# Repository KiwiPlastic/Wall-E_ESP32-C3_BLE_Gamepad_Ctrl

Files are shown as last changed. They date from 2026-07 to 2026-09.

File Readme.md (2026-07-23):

# Wall-E ESP32-C3 with BLE Game Controller (Xbox controler)
Thie is an upgrade to the Wall-E project developed by Chillbasket

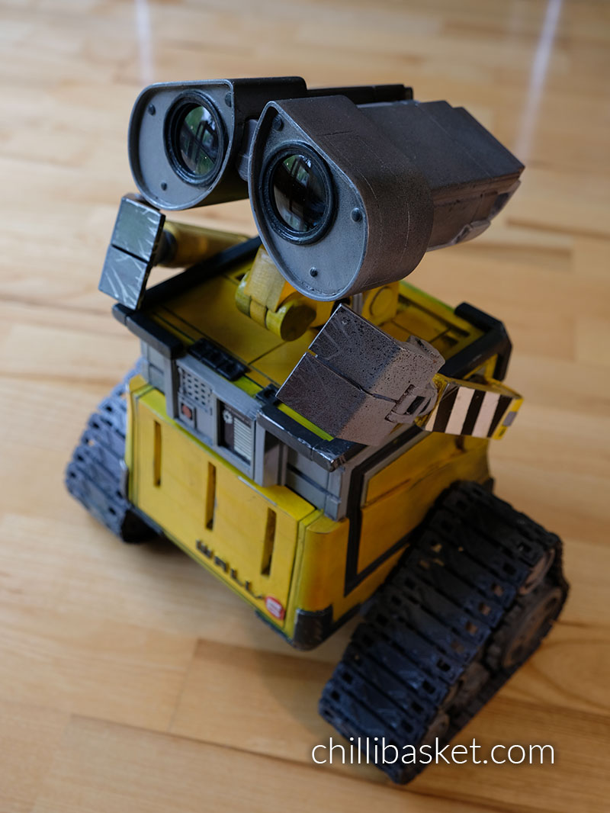
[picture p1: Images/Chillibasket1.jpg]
Walle-E Chillibasket


## 🚀 Upgrades and Features
  -	Web Server removed
  -	Added BLE Gamepad controller – Xbox controler 2026
  -	Added working Top buttons
  -	Added Bay Door Servo
  -	Controllable Bay LED light
  -	Electronics Platform – frees up Bay so can have a boot and plant etc
  -	RGB mood LED
  -	1.44 Oled feedback display
  -	All existing avaliable upgrade prints have been used and are included.
  - The only changed one is the top cover to accomidate pushbuttons
  
•	10 DOF:-
  -	Arms (2)
  -	Neck (2)
  -	Head Rotation (1)
  -	Eyes (2) 
  -	Eye Borrows (2)
  -	Bay Door (1)

•	Size:	H = 338		W = 291	D = 186

## 📦 Build & Installation

•	See this link for Wall-E Assembly Instructions and Videos by Chillbasket (https://wired.chillibasket.com/3d-printed-wall-e/) 

### Hardware: -
    1 x ESP32-C3
    1 x I2C PCA9685 16-Channel 12-bit PWM Servo Motor Driver Module
    1 x I2C PCF 8575 I/O Multiplexer
    1 x Audio Module - Mini MP3 Player Audio Module (DFPLayer)
    1 x mini-Speaker 8 or 4 ohm 3watt
    1 x 1.44 I2C OLED Display
    1 x 10mm RGB LED – common cathode 
    4 x Tactile Pushbutton with LED
    4 x 150R resistor
    1 x 4K7 Resistor
    3 x Logic Level Shifter 3v to 5v 
    1 x L298N Dual H Bridge DC Motor Driver
    10 x MG90S metal gear servos
    2 x 37mm motor with gearbox, offset shaft, 25kg, 150 rpm (Not cheap ones)
    1 x LR7843 Mosfet module
    1 x MP1482 min buck set to 2v
    1 x 1watt or 3watt LED (torch head light LED)
    2 x Buck 5amp Set to 5v and 6v
    1 x 10amp auto reset fuse
    1 x XT60 Male Connector
    16 x Bearings 10 x 15 x 4
    Misc. M3 bolts, nuts, heat inserts, heat shrink

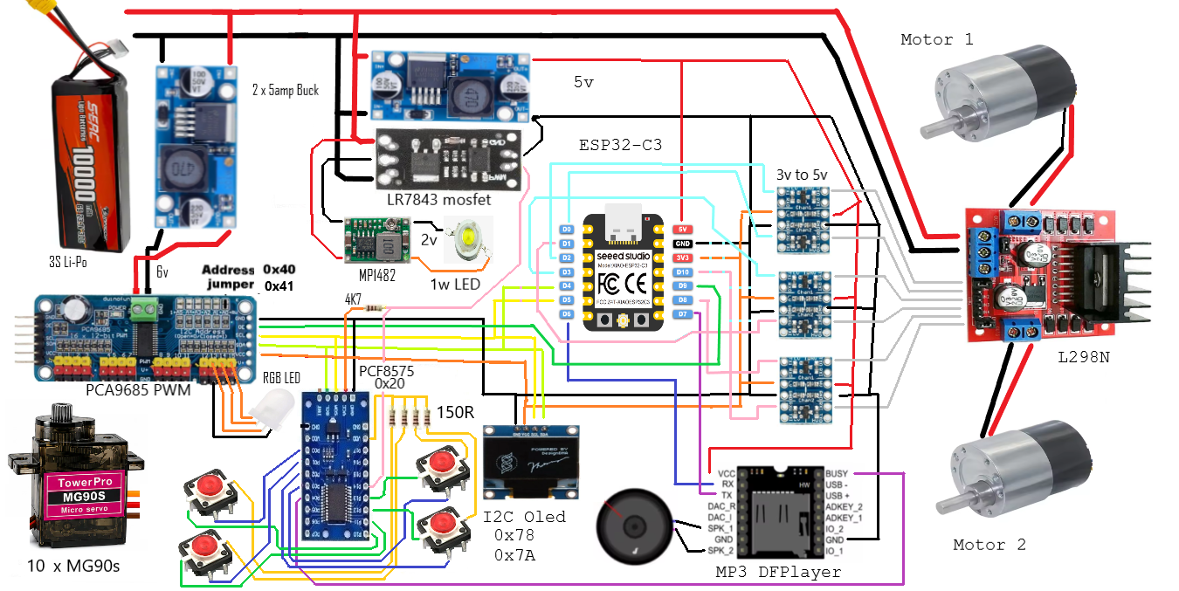
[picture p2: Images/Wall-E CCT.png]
circuit


### Servo Channel List: -
    0 Head Rotation
    1 Neck Top
    2 Neckk Bottom
    3 Eye Right
    4 Eye Left
    5 Arm Left
    6 Arm Right
    7 Eye Brow Right
    8 Eye Brow Left
    9 Bay Door
    10
    11
    12
    13 RED RGB LED
    14 GRN RGB LED
    15 BLU RGB LED



Use common Cathod 10mm RGB LED

### Notes: -
    - All moving joints need to be sanded and made to work as smoothly as possible
    - Silicon from (Starlink Installations) is useful on these joints
    - Power up PSU and adjust Bucks to 5v, 6v and 2v BEFORE connecting to main loom
    - Wire up loom and electronics, then test before securing to 3d prints
    - glue electronics floor brakets so floor is level with top of Bay door opening
    - Secure electronics to 3d prints
    - Power up with no Motor or Servo loads, test buttons, leds, oled, MP3 player, xbox controller is working
    - Connect servos and put calibration firmware in ESP32 and perform calibration (https://wired.chillibasket.com/3d-printed-wall-e/)
    - Edit main wall-E firmware to add the calibration values from IDE serial monitor, transfer to ESP32 
    - Power up Wall-E, with game controler off
    - Turn on Game controller, should enrol automatically, watch Oled
    - Test and go for gold
    - Note: Theres no Battery monitor in this code. Use a Li-Po battery monitor/buzzer on Li-Po monitor plug 






### Arduino IDE will require these library's
    - BLE-Game_Client by Tomaz bekas V0.12.1
    - ESP_Software_Serial by Dirk Kaar SNDVAPS 8.3.1
    - Adafruit SSD1306 by Adfruit v2.5.17
    - Adafruit PWM Servo Driver lib by Adfruit v 3.03 
    - Adafruit PCF8574 by Adfruit v 1.1.2
    - DFRobotDFPlayerMini by DFRobot v1.0.6
    - Wire.h - I2C library driver, Could be built into IDE Library’s

Note: at time of writting the BLE-Game_Client required a small edit in a txt file to get it working. (https://github.com/tbekas/BLE-Gamepad-Client/pull/122)
It will be fixed in newer version releases, so this edit will not always be required.

## 🛠️ Usage

### Top Push Buttons Functions: -
    RED PB - Play Prev 
    GRN PB - Play Next
    ORG PB – Autonomous Servos On/Off 
    WHT PB – Bay Door Open/Close
    
### BLE Gamepad - Xbox controler - Button Map :-
    Tracks turn left/right  	Left Stick X (hoz)      
    Tracks forward/back       Left Stick Y (Vert) 
    Head rotation           	Right Stick X
    Head Up/Down            	Right Stick Y
    Neck Bottom             	Button A + Dpad Up/Dwn
    Lhs Eye                 	Button X + Dpad Up/Dwn
    Lhs Eyebrow             	Button X + Dpad Left/Right
    Rhs Eye                 	Button B + Dpad Up/Dwn
    Rhs Eyebrow             	Button B + Dpad Left/Right
    Bay Door Open/Close      	Button Y + Dpad Left Right
    Left Arm               	  Left Trigger  + Dpad Up/Dwn
    Right Arm              	  Right Trigger + Dpad Up/Dwn
    Play Sound              	Left Bumper + Dpad Left/Right - can crash
    Motor dead zone         	Left Bumper + Dpad Up/Dwn - 0 to 250
    LEDS move               	Right Bumper + Dpad Left/Right - loop x 4
    Steering Offset         	Right Bumper + Dpad Up/Dwn -  -100 to 100
    Animation Number          ViewButton +  Dpad Up/Dwn
    Automonus Mode    	      MenuButton On/Off toggel
    Dpad Up                 	adjust up
    Dpad Down               	adjust down
    Dpad Left               	adjust left
    Dpad Right              	adjust right
    Left Stick Button
    Right Stick Button
    ShareButton
    XboxButton

## 📜 License
Distributed under the MIT License. See `LICENSE` for more information.

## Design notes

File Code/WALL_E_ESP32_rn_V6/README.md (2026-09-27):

/* * * * * * * * * * * * * * * * * * * * * * *
 *
 * Upgraded Code by:  Richard Nicholson
 * Email:    richn01@msn.com
 * based on the original project and code from Simon Bluett ( hello@chillibasket.com )
 * Version:  6.0
 * Date:     18-9-2026
 * Copyright (C) 2020, MIT License
 *
 * HOW TO USE:
 * 1. Install the following library's
 *    In the Arduino IDE, on the left, click the libary manager icon
 *       BLE-Game_Client by Tomaz bekas V0.12.1
 *       ESP_Software_Serial by Dirk Kaar SNDVAPS 8.3.1
 *       Adafruit SSD1306 by Adfruit v2.5.17
 *       Adafruit PWM Servo Driver lib by Adfruit v 3.03 
 *       Adafruit PCF8574 by Adfruit v 1.1.2
 *       DFRobotDFPlayerMini by DFRobot v1.0.6
 *       I2C Wire driver, Could be built in to IDE 
 *    
 * 2. Calibrate the servo motors, using the calibration sketch provided in the
 *    GitHub repository. Paste the calibrated values between lines 296 to 305.
 * 3. Upload the sketch to the micro-controller, and open the serial monitor 
 *    at a baud rate of 115200.
 * 4. Turn Game Pad on, should automaticaly enrol
 * 5. Additional instructions and hints can be found at:
 *    https://wired.chillibasket.com/3d-printed-wall-e/
 *
 * * * * * * * * * * * * * * * * * * * * * * *

Summary of upgardes
 - Removed web server and associated libarys due to documented memory leak
 - Got Track motors working correctly
 - Got DFPlayer starting more reliably
 - Added I2C Oled display
 - Added I2C PCF8575 I/O Expander
 - Added BLE Gamepad controler libaray, note needs edit in c++ files to get working
 - Fixed Hardware crash coursed by BLE driver. Hardware serial for DFPlayer stopped working
 - Added ESP_Soft_Serial, DFPayer working with BLE driver (Xbox)
 - Expose all xbox buttons and vibration
 - Map xbox buttons to Wall-E CLI servos and controls
 - Added 4 x Push Buttons and LEDs
 - Added DFPlay Busy feed back via PCF8575
 - Added Bay Door Servo
 - Added Bay LED light
 - Added RGB mood LED on PWM module
 - Added different simple Oled display
 - RGB Led
 
NOTE: BLE Controler should be OFF on Wall-E Power up
 
// BLE Gamepad - Xbox controler - button map     Needs updating 18-9-26
    Tracks turn left/right  Left Stick X (hoz)      
    Tracks forward/back     Left Stick Y (Vert) 
    Head rotation           Right Stick X
    Head Up/Down            Right Stick Y
    Neck Bottom             Button A + Dpad Up/Dwn
    Lhs Eye                 Button X + Dpad Up/Dwn
    Lhs Eyebrow             Button X + Dpad Left/Right
    Rhs Eye                 Button B + Dpad Up/Dwn
    Rhs Eyebrow             Button B + Dpad Left/Right
    Door Open/Close         Button Y + Dpad Left Right
    Left Arm                Left Trigger  + Dpad Up/Dwn
    Right Arm               Right Trigger + Dpad Up/Dwn
    Play Sound              Left Bumper + Dpad Left/Right - can crash
    Motor dead zone         Left Bumper + Dpad Up/Dwn - 0 to 250
    LEDS move               Right Bumper + Dpad Left/Right - loop x 4
    Steering Offset         Right Bumper + Dpad Up/Dwn -  -100 to 100
    Animation Number        ViewButton +  Dpad Up/Dwn
    Automonus Servo Mode    MenuButton On/Off toggel
    Dpad Up                 adjust up
    Dpad Down               adjust down
    Dpad Left               adjust left
    Dpad Right              adjust right
    Left Stick Button
    Right Stick Button
    ShareButton
    XboxButton

 // LED Push Buttons on Front
    RED_PB = Play Prev
    GRN_PB = PlaY current
    ORG_PB = Play next
    WHT_PB = Door Open/Close

 //  CLI
    Wn -100 to 100 Motor turn Left/Right Ctrl
    Yn -100 to 100 Motor Forward/Reverse
    sn -100 to 100 Steering Offset
    On 0 to 250 Motor dead zone
    An  Animation number 
    Mn  0 to 1 Autoomonus Servo Mode on/off
    Ln 0 to 100 Left Arm move 
    Rn 0 to 100 Right Arm Movement
    Bn 0 to 100 Neck Bottom
    Tn 0 to 100 Neck Top        
    Gn 0 to 100 Head Rotation
    En 0 to 100 Lhs Eye
    Un 0 to 100 Rhs Eye
    Cn 0 to 100 Lhs Eyebrow
    Vn 0 to 100 Rhs Eyebrow
    Dn 0 to 1 Door open/close
    w Move forwrad
    q Stop
    s Backward
    a Drive & look Left
    d Drive and look Right
    j Left head Tilt
    l Right Head tilt
    i Sad Head
    k Head Neutral
    f Head Up
    g Head Forward
    h Head Down
    b LHS Arm Low,RHS Arm up
    n Both Arms Natural
    m left arm high,right arm low
    !n play sound n (not 0 will crash) - oled
    vn Volume n 0-30? - ole

 // PWM Mux channel #
    0 Head Rotation
    1 Neck Top
    2 Neckk Bottom
    3 Eye Right
    4 Eye Left
    5 Arm Left
    6 Arm Right
    7 Eye Brow Right
    8 Eye Brow Left
    9 Door
    10
    11
    12
    13 RED RGB LED
    14 GRN RGB LED
    15 BLU RGB LED

//---------------------------------------------------------------
 * @following shows calls into DFPlayer.  eg myDFPlayer.play(number); 
 * @file DFRobotDFPlayerMini.h 

  #define DFPLAYER_EQ_NORMAL 0
  #define DFPLAYER_EQ_POP 1
  #define DFPLAYER_EQ_ROCK 2
  #define DFPLAYER_EQ_JAZZ 3
  #define DFPLAYER_EQ_CLASSIC 4
  #define DFPLAYER_EQ_BASS 5

  #define DFPLAYER_DEVICE_U_DISK 1
  #define DFPLAYER_DEVICE_SD 2
  #define DFPLAYER_DEVICE_AUX 3
  #define DFPLAYER_DEVICE_SLEEP 4
  #define DFPLAYER_DEVICE_FLASH 5

  #define DFPlayerCardInserted 2
  #define DFPlayerCardRemoved 3
  #define DFPlayerCardOnline 4
  #define DFPlayerPlayFinished 5
  #define DFPlayerError 6
  #define DFPlayerUSBInserted 7
  #define DFPlayerUSBRemoved 8
  #define DFPlayerUSBOnline 9
  #define DFPlayerCardUSBOnline 10
  #define DFPlayerFeedBack 11
  
  //---- can call these 
  
  void setTimeOut(unsigned long timeOutDuration);
  
  void next();
  
  void previous();
  
  void play(int fileNumber=1);    // eg myDFPlayer.play(number); 
  
  void volumeUp();
  
  void volumeDown();
  
  void volume(uint8_t volume);
  
  void EQ(uint8_t eq);
  
  void loop(int fileNumber);
  
  void outputDevice(uint8_t device);
  
  void sleep();
  
  void reset();
  
  void start();
  
  void pause();
  
  void playFolder(uint8_t folderNumber, uint8_t fileNumber);
  
  void outputSetting(bool enable, uint8_t gain);
  
  void enableLoopAll();
  
  void disableLoopAll();
  
  void playMp3Folder(int fileNumber);
  
  void advertise(int fileNumber);
  
  void playLargeFolder(uint8_t folderNumber, uint16_t fileNumber);
  
  void stopAdvertise();
  
  void stop();
  
  void loopFolder(int folderNumber);
  
  void randomAll();
  
  void enableLoop();
  
  void disableLoop();
  
  void enableDAC();
  
  void disableDAC();
  
  int readState();
  
  int readVolume();

  int readEQ();
  
  int readFileCounts(uint8_t device);
  
  int readCurrentFileNumber(uint8_t device);
  
  int readFileCountsInFolder(int folderNumber);
  
  int readFileCounts();

  int readFolderCounts();
  
  int readCurrentFileNumber();

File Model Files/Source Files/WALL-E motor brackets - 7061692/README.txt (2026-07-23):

WALL-E motor brackets by DreadPirateBoberts on Thingiverse: https://www.thingiverse.com/thing:7061692

Summary:
These are modified motor brackets for the Chillibasket WALL-E replica. The brackets allow for a stronger, more secure mounting of the drive motors. They are now one piece design, 1.5 mm longer, provision for two motor mounting bolts. The drive pinion has also been modified to allow for better clearance of the grub screw.

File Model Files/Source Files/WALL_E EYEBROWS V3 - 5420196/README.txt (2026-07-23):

#ChilliBasket WALL_E EYEBROWS V3 by DaddieMon on Thingiverse: https://www.thingiverse.com/thing:5420196

Summary:
This is the upgraded files (version 3)...the files I accidentally uploded on here:https://www.thingiverse.com/thing:5383714/comments#comment-6503123are my first remix... sorry for the mess...Please check on the version3.I used CURA 5.0v slicer.Hope this will work for you.

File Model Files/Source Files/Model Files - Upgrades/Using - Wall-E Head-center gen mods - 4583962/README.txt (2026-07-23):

Wall-E Head-center mod by rene1960 on Thingiverse: https://www.thingiverse.com/thing:4583962

Summary:
I uploaded some modifications to the neck assembly, added a screw-hole (for 3mm x 6mm screw) to mount the Head-center to the neck-round-top so you don't have to glue it to the neck-round-top, use 3mm x 8mm screws to put the neck-round-top left and right part together.Made some small holes in the neck-round-bottom and neck-top to screw it together with a 2mm self-tapping screw. More space in the neck-bottom-right for servo cables, use 3mm x 8mm screw to assemble the neck-bottom right and left, I use glue to hold the nut in place.I modified the eye-back-left and right to make more space for the servo-horns to move.A modification is made to the body-front and body-front-door, I added holes for magnets (neodyne magnet 6mm x 3mm) to keep the front-door closed.Made two holes in the body top for the cables.Made a flenge to the arm hinge axle so you don't have to glue in to the hinge.Credits for my friend Ben for the redesign of the head-center part and the solar charge panel.

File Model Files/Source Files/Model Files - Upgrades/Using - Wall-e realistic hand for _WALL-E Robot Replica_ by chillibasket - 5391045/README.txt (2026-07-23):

Wall-e realistic hand for "WALL-E Robot Replica" by chillibasket by Wujek_k on Thingiverse: https://www.thingiverse.com/thing:5391045

Summary:
Wall-e hands for for "WALL-E Robot Replica" by chillibasket.They fit to original for "WALL-E Robot Replica" by chillibasket and are scaled to fit "sockets" in Wall-e body, no changes to original model are needed.Print two copies, drill holes to the required dimension (1.8 for fingers hinges), use support.Each finger can be moved separately and the thumb is mounted on the sphere pivot what allows to move it in any desired position.For hinges axles use filament, cut to dimenstion +1mm on each side, melt it using soldering iron or just a torch and flatten it with any cold metal object.Print, assemble, paint, mount to Wall-e using glue.

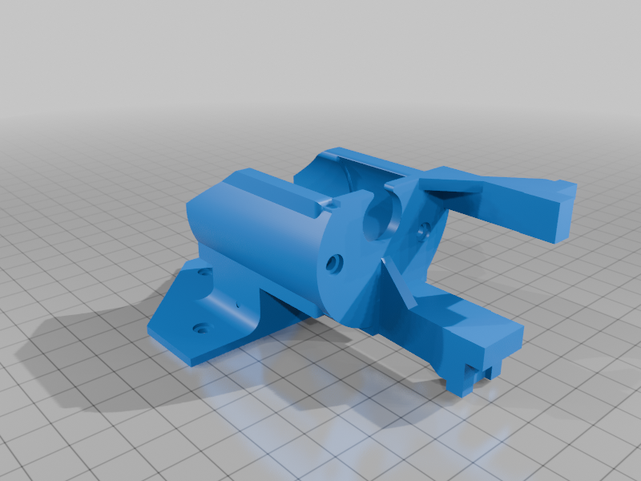
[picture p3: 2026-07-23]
Model Files/Source Files/WALL-E motor brackets - 7061692/images/Left_motor_bracket_redesign_v4.png

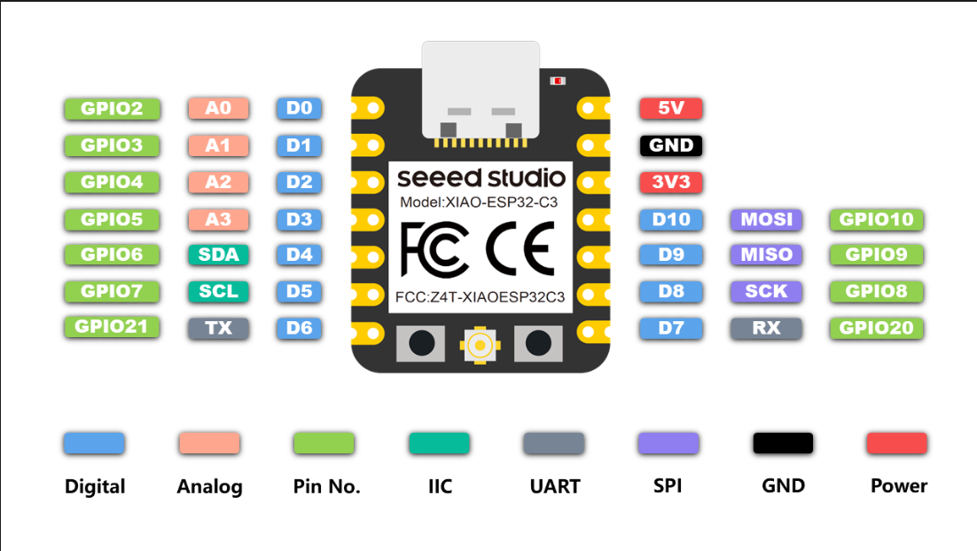
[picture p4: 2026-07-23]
Images/ESP32-C3 pinout.png

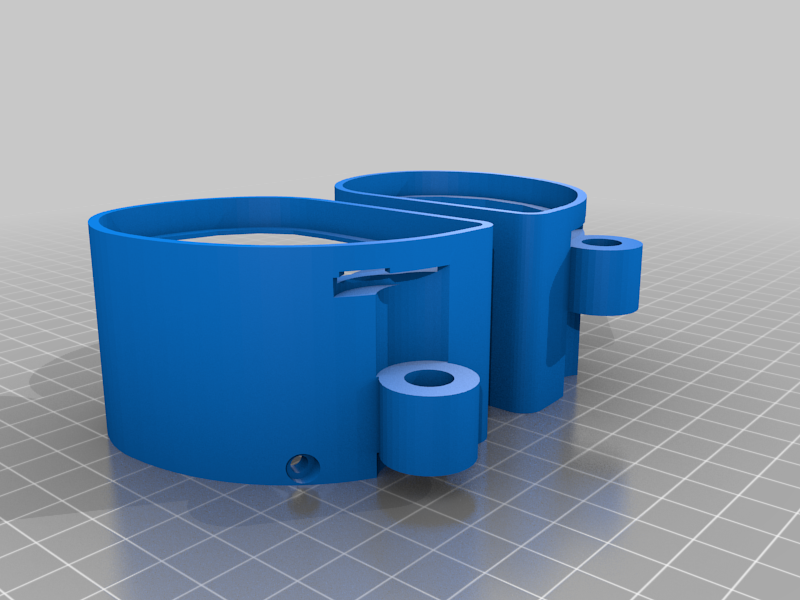
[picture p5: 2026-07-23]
Model Files/Source Files/WALL_E EYEBROWS V3 - 5420196/images/UPDATED_EYES-HOUSING__LR_V3.png

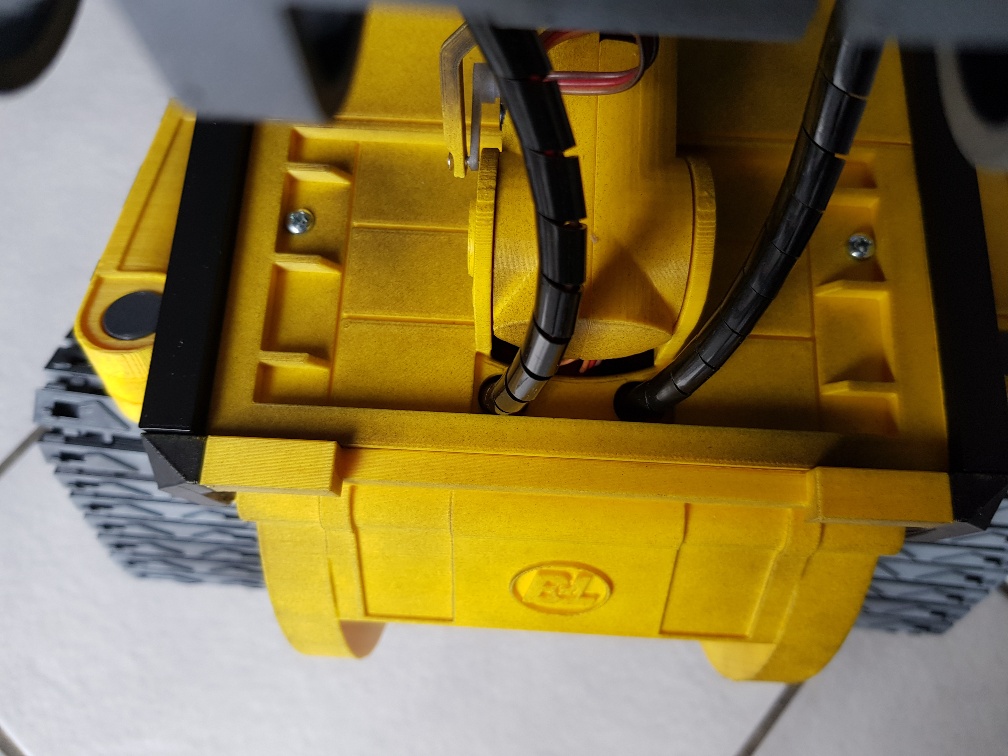
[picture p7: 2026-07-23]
Model Files/Source Files/Model Files - Upgrades/Using - Wall-E Head-center gen mods - 4583962/images/walle-body-top-holes.jpg

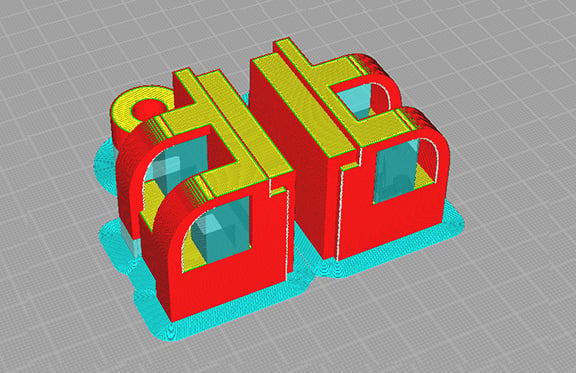
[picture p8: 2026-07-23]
Model Files/Source Files/WALL_E EYEBROWS V3 - 5420196/images/REAR_CAP.jpg

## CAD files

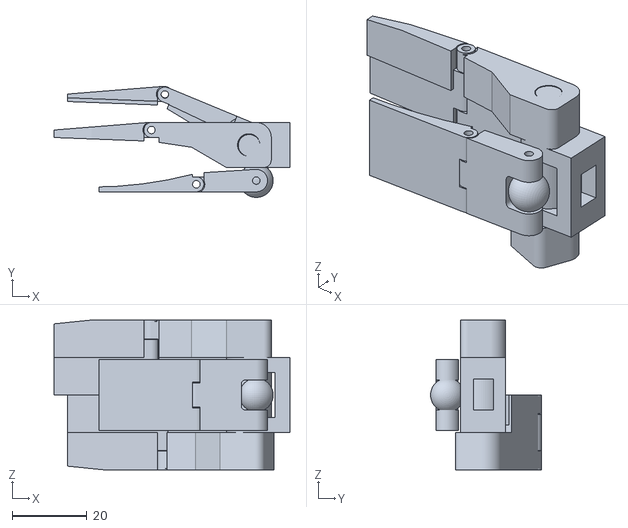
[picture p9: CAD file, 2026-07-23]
Model Files/Source Files/Model Files - Upgrades/Using - Wall-e realistic hand for _WALL-E Robot Replica_ by chillibasket - 5391045/files/Wall-e_hand_assembled.stl
63.0 x 29.6 x 40.0

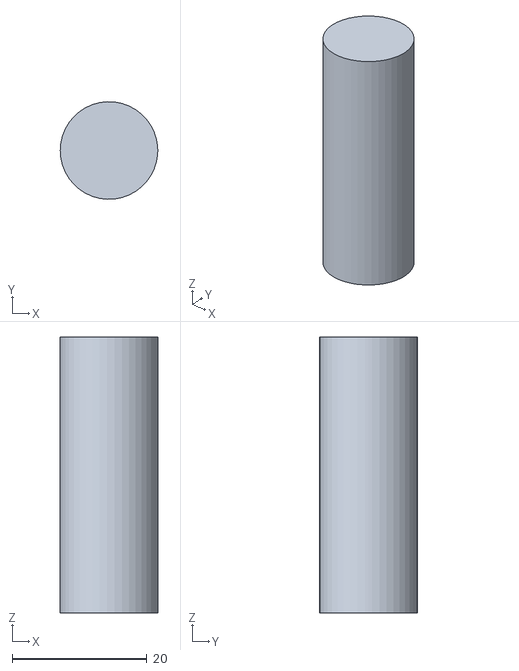
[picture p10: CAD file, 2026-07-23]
Model Files/neck-bottom-axle.stl
14.5 x 14.5 x 41.0

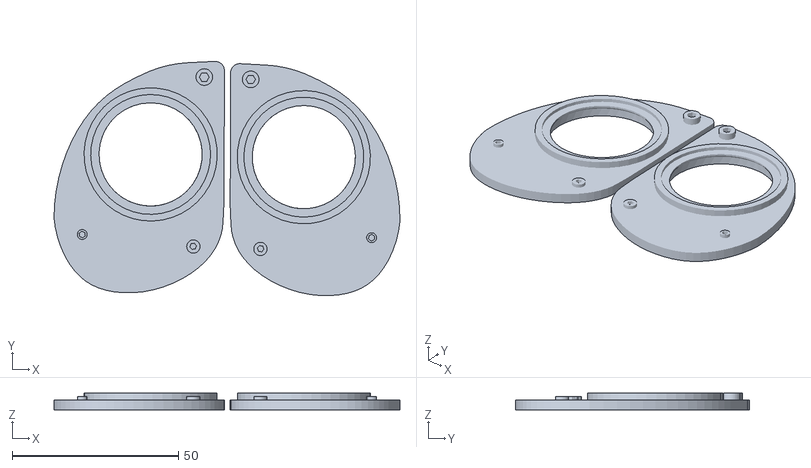
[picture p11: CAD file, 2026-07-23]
Model Files/Source Files/Eyes upgrade - damaged files/EYES_FLAT_COVER_LR_V3.stl
103.9 x 70.3 x 5.04

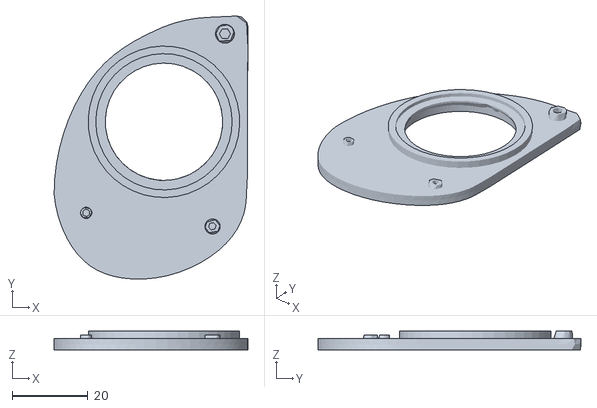
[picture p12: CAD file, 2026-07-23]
Model Files/Source Files/Model Files - ESP32 remix/updated__eyes_flat_cover_lr_v3_hb35.stl
51.2 x 69.5 x 5.00

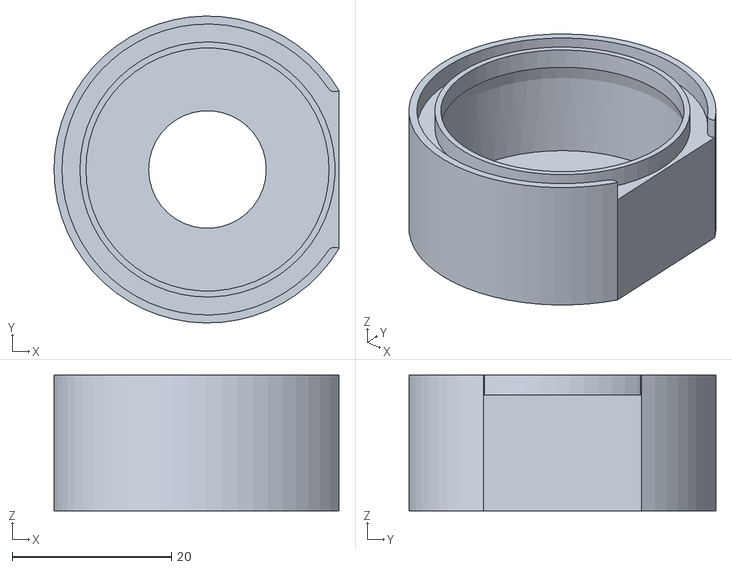
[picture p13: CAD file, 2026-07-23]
Model Files/Source Files/Model Files - Mr Prints/eye-camera-mount.stl
35.8 x 38.5 x 17.0

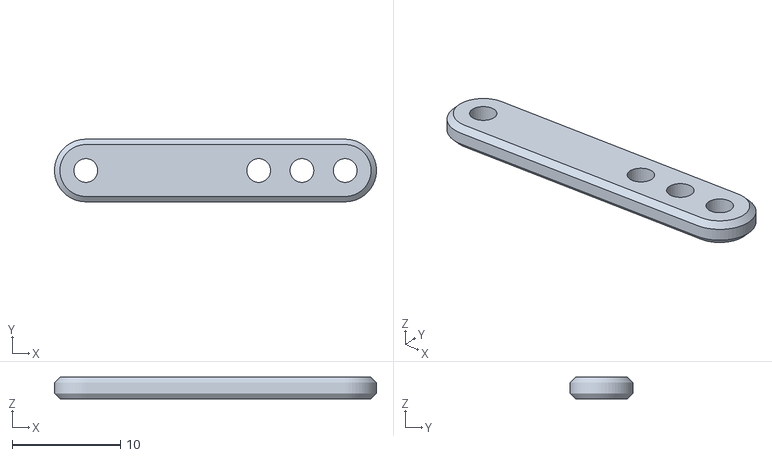
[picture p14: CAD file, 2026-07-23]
Model Files/Source Files/Model Files - Upgrades/Using - WALL-E (head eye linkage arms) - 4707426/files/Linkage_MKIII.stl
29.8 x 5.80 x 2.00

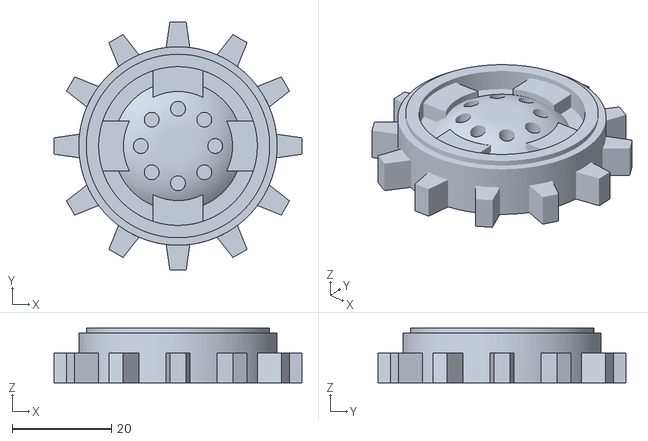
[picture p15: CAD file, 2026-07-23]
Model Files/Source Files/Model Files - Upgrades/Using - WALL-E (Tracks strong linkages) - 4932310/files/wheel-frontx4_MKII.stl
50.0 x 50.0 x 11.0

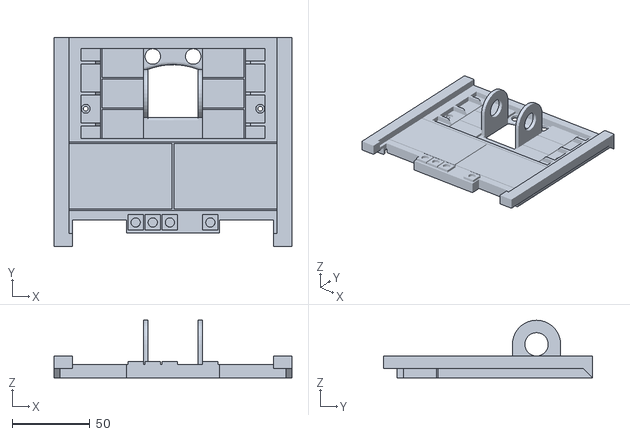
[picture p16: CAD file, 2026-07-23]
Model Files/Source Files/Model Files - Upgrades/Using - Wall-E Head-center gen mods - 4583962/files/body_top_holes.stl
153.0 x 134.4 x 37.0

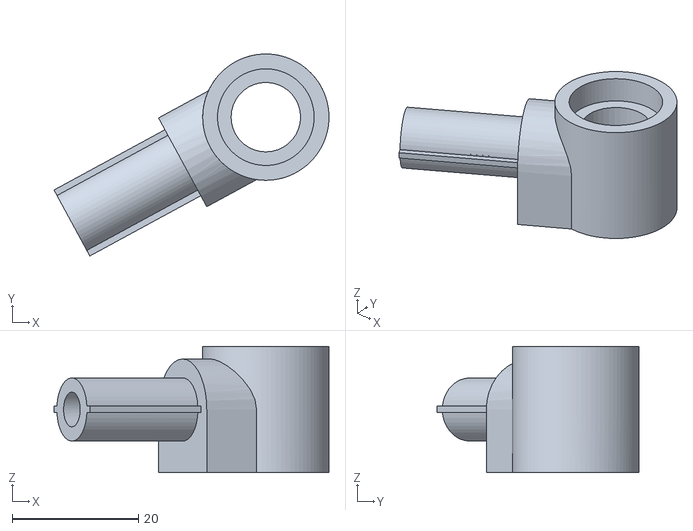
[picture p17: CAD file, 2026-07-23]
Model Files/Source Files/Model Files - Upgrades/Using - WALL-E modified wheel frame with spring and bearings - 4832742/files/functional_part_x_2.stl
43.5 x 32.0 x 20.0

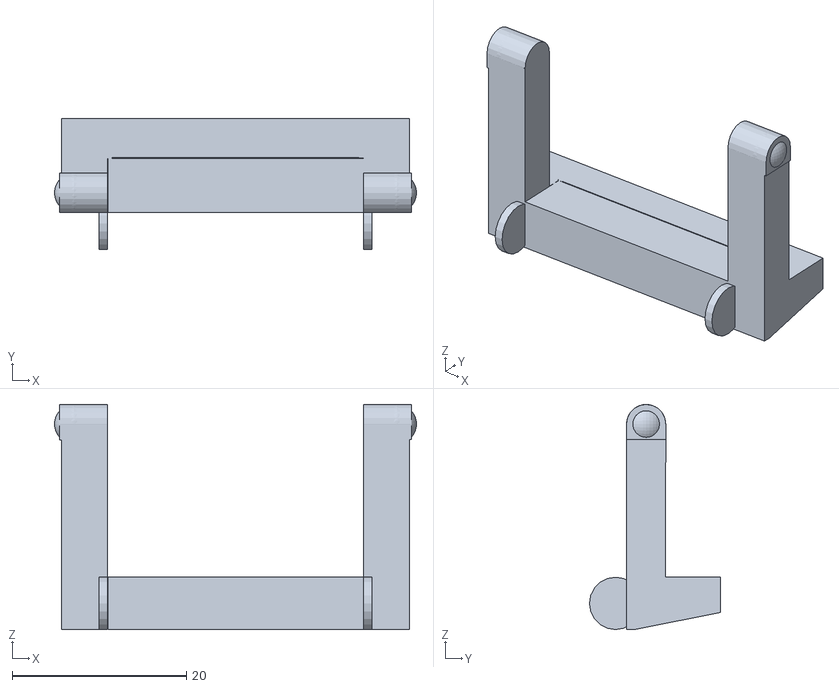
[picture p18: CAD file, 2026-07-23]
Model Files/Source Files/Model Files - Upgrades/Using - WALL-E Robot Replica - Rear Door/files/hook.stl
41.5 x 15.0 x 25.8

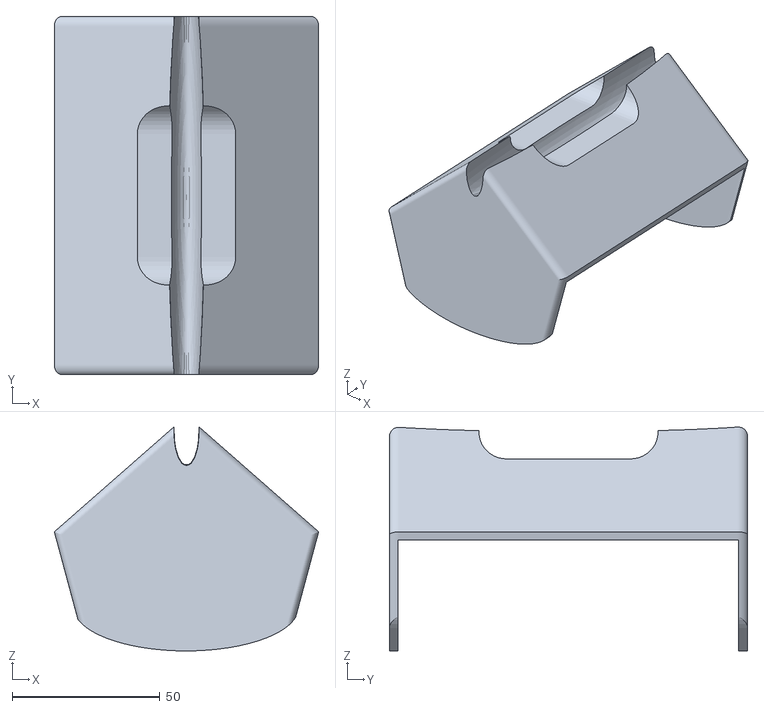
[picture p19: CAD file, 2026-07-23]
Model Files/Source Files/Wall-E Buy and Large Cooler Box - 4141026/files/BL-Cooler_Box-2.stl
89.4 x 121.0 x 75.7

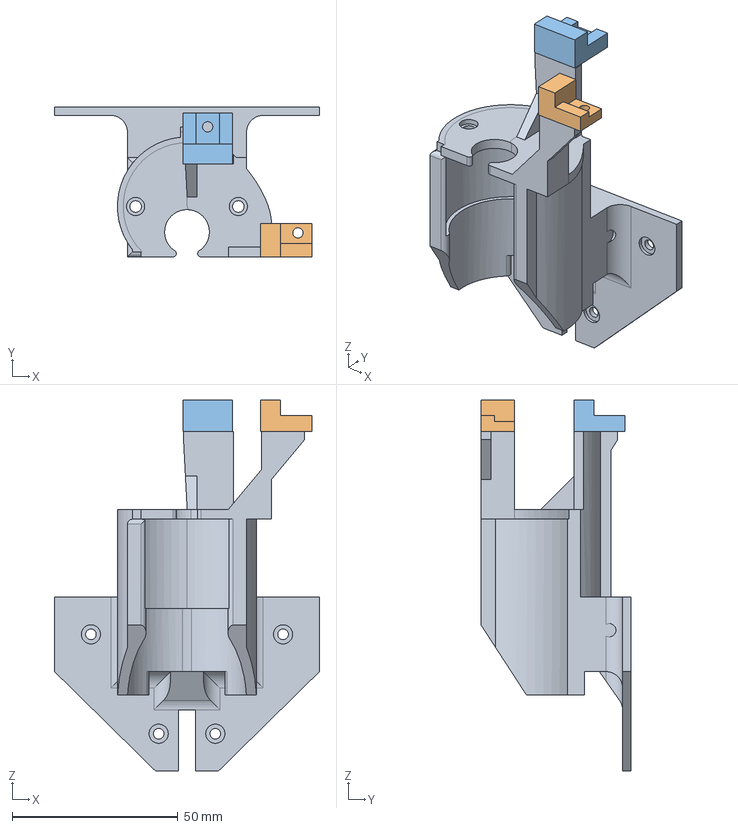
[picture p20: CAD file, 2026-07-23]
Model Files/Source Files/WALL-E motor brackets - 7061692/files/Right_motor_bracket_redesign_v4.step
80.0 x 45.2 x 112.0 mm
wheel-bracket-inner-right-3
wheel-bracket-outer-right-3

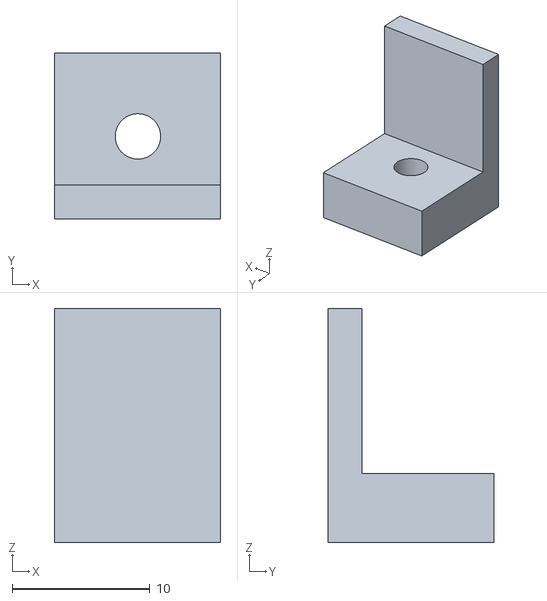
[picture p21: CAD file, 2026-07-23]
Model Files/body-elect-mount FL.stl
12.1 x 12.1 x 17.0

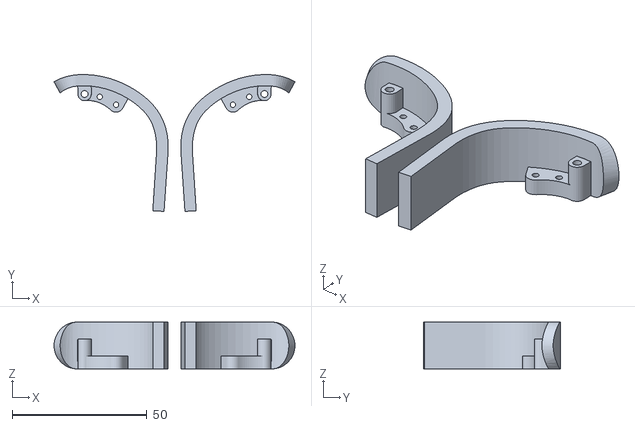
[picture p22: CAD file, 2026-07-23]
Model Files/Source Files/Eyes upgrade - damaged files/EYES-EYEBROWS_LR_V3.stl
89.3 x 50.8 x 17.4

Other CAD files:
Model Files/Source Files/Model Files - ESP32 remix/body-front-door-mod-hb.stl
Model Files/Source Files/Model Files - Mr Prints/body-neck-servo-holder.stl
Model Files/Source Files/Model Files - Upgrades/Using - WALL-E (head eye linkage arms) - 4707426/files/Head_Center_MKIII.stl
Model Files/BL-Cooler_Box-3.stl
Model Files/BL-Cooler_Box.stl
Model Files/Body-front LED bezzel.stl
Model Files/Body_electronis_Floor.stl
Model Files/Eye _RHS_Front.stl
Model Files/Eye_LHS_Front.stl
Model Files/Eye_LHS_Middle.stl
Model Files/Eye_LHS_Rear.stl
Model Files/Eye_RHS_Flap.stl
Model Files/Eye_RHS_Rear.stl
Model Files/Hand - rivit bottom.stl
Model Files/Hand_parts_x2.stl
Model Files/Head-axle.stl
Model Files/Head-linkage_mkiii_hb.stl
Model Files/Head_Center_MKIII.stl
Model Files/Source Files/Eyes upgrade - damaged files/EYES-HOUSING__LR_V3.stl
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

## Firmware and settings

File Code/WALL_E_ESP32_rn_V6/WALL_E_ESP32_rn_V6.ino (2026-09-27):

#define VERSION 6.0  // 23-9-26
/* * * * * * * * * * * * * * * * * * * * * * *
 *
 * Upgraded Code by:  Richard Nicholson
 * Email:    richn01@msn.com
 * based on the original project and code from Simon Bluett ( hello@chillibasket.com )
 * Version:  5.0
 * Date:     23 July 2026
 * Copyright (C) 2020, MIT License
 *
 * HOW TO USE:
 * 1. Install the following library's
 *   In the Arduino IDE, on the left, click the libary manager icon
 *      BLE-Game_Client by Tomaz bekas V0.12.1
 *      ESP_Software_Serial by Dirk Kaar SNDVAPS 8.3.1
 *      Adafruit SSD1306 by Adfruit v2.5.17
 *      Adafruit PWM Servo Driver lib by Adfruit v 3.03 
 *      Adafruit PCF8574 by Adfruit v 1.1.2
 *      DFRobotDFPlayerMini by DFRobot v1.0.6
 *      I2C Wire driver, Could be built in to IDE 
 *    
 * 2. Updload the Calibrate.ino sketch and calibrate the servo motors
 *    Copy and Paste the output from Calibration, into Wall-E code between lines 296 to 305.
 8      Additional instructions and hints can be found at:
 *      https://wired.chillibasket.com/3d-printed-wall-e/
 *
 * 3. Upload the Wall-E sketch to the ESP32C3, and open the serial monitor 
 *    at a baud rate of 115200.
 *
 * 4. Turn Game Pad on, should automaticaly enrol, will display on LCD and serial monitor
 *
 * * * * * * * * * * * * * * * * * * * * * * *

NOTE: BLE Controler should be OFF on Wall-E Power up, else DFPlayer might not start
 
  // BLE Gamepad - Xbox controler - button map
    Tracks turn left/right  Right Stick X (hoz)      
    Tracks forward/back     Right Stick Y (Vert) 

    Head rotation           Left Stick X
    Head Bottom             Right Stick Y
    Neck Top                Button A + Left Stick Y
    Lhs Eye                 Button X + Left Stick y
    Rhs Eye                 Button B + Left Stick y
    
    Left Arm                Left Trigger  + Left Stick y
    Right Arm               Right Trigger + Left Stick y

    Lhs Eyebrow             Left Bumper On = brow up
    Rhs Eyebrow             Right Bumper On = brow up

    Door Open/Close         Button Y toggel
    Play Sound              LTrigger + RTrigger + Dpad Up/Dwn
    Motor dead zone         ViewButton + Dpad Up/Dwn - 0 to 250
    Steering Offset         ShareButton + Dpad Up/Dwn -  -100 to 100
    Animation Number        MenuButton +  Dpad Up/Dwn
    Automonus Servo Mode    Right Stick PB On/Off toggel

    Dpad Up                 adjust up
    Dpad Down               adjust down
    Dpad Left               adjust left
    Dpad Right              adjust right

    Left Stick Button
    Right Stick Button      Automonus Mode On/Off toggel
    ViewButton
    MenuButton
    ShareButton
    XboxButton

 // LED Push Buttons on Front
    RED_PB = Play Previous
    GRN_PB = PlaY
    ORG_PB = Play Next
    WHT_PB = Door Open/Close

 //  CLI
    Wn -100 to 100 Motor turn Left/Right Ctrl
    Yn -100 to 100 Motor Forward/Reverse
    sn -100 to 100 Steering Offset
    On 0 to 250 Motor dead zone
    An  Animation number 
    Mn  0 to 1 Autoomonus Servo Mode on/off
    Ln 0 to 100 Left Arm move 
    Rn 0 to 100 Right Arm Movement
    Bn 0 to 100 Neck Bottom
    Tn 0 to 100 Neck Top        
    Gn 0 to 100 Head Rotation
    En 0 to 100 Lhs Eye
    Un 0 to 100 Rhs Eye
    Cn 0 to 100 Lhs Eyebrow
    Vn 0 to 100 Rhs Eyebrow
    Dn 0 to 1 Door open/close
    w Move forwrad
    q Stop
    s Backward
    a Drive & look Left
    d Drive and look Right
    j Left head Tilt
    l Right Head tilt
    i Sad Head
    k Head Neutral
    f Head Up
    g Head Forward
    h Head Down
    b LHS Arm Low,RHS Arm up
    n Both Arms Natural
    m left arm high,right arm low
    !n play sound n (not 0 will crash) - oled
    vn Volume n 0-30? - ole

 // PWM Mux channel #
    0 Head Rotation
    1 Neck Top
    2 Neckk Bottom
    3 Eye Right
    4 Eye Left
    5 Arm Left
    6 Arm Right
    7 Eye Brow Right
    8 Eye Brow Left
    9 Door
    10
    11
    12
    13 RED RGB LED
    14 GRN RGB LED
    15 BLU RGB LED

 // Servos
    Pwm range is 0-4096 (12 bit) recommended range 150 min 700 max @ 60hz
    We work in percent 0-100
    Use calibration prog to set high and low position
    Default servo positions are set from animation (0); 
*/

// ====================================================================================

//#include <Arduino.h>
#include <BLEGamepadClient.h>         // Blue Tooth Xbox 1 controler
#include <SoftwareSerial.h>           // ESP_Software_Serial by Dirk Kaar SNDVAPS 8.3.1
#include <Wire.h>                     // I2C Driver
#include <SSD1306AsciiWire.h>         // I2C Oled display
#include <Adafruit_PWMServoDriver.h>  // I2C PWM Servo Driver
#include <Adafruit_PCF8575.h>         // I2C IO Expander
#include "Queue.hpp"                  //
#include "MotorControllerL298.hpp"    // L298 Tracks Motor Sheild
#include "DFRobotDFPlayerMini.h"      // MP3 DFPlayer

// BIOS ESP32-C3
#define DIRA1 D0             // 12v Motors with L298N
#define DIRB1 D1             // 12v Motors with L298N
#define ENABLE1 D2           // 12v Motors with L298N
#define DIRA2 D3             // 12v Motors with L298N
#define PIN_SDA D4           // PCA9685 I2C servo mux. used without definition
#define PIN_SCL D5           // PCA9685 I2C servo mux.  used without definition
#define DFPLAYER_TX_PIN D6   // DFPlayer Communication use Resitors 1k-gnd, 660, VCC
#define DFPLAYER_RX_PIN D7   // DFPlayer Communication
#define DIRB2 D10            // 12v Motors with L298N
#define SERVO_ENABLE_PIN D9  // Servo shield output enable pin, | Bootstrap
#define ENABLE2 D8           // 12v Motors with L298N | Bootstrap

// D8/D9 Bootstap pins must be high at Power Up/Boot
// pinMode(LED_BUILTIN, OUTPUT);  // Config Built in Led as an output. NOT avaliable ON C3

// PCF8575 I2C I/O Expander
#define PIN_RED_PB 0    // input
#define PIN_GRN_PB 1    // in
#define PIN_ORG_PB 2    // in
#define PIN_WHT_PB 3    // in
#define PIN_DFP_BUSY 4  // in
#define PIN_WHT_LED 8   // PB out
#define PIN_ORG_LED 9   // PB out
#define PIN_GRN_LED 10  // PB out
#define PIN_RED_LED 11  // PB out
#define PIN_BAY_LED 12  // outout is active low, Mosfet is active high. HIGH = Mosfet on

// Servo Default poistions 0 - 100
#define S0_HEAD_DPOS 50     // Servo 0 Head Rotation Center
#define S1_NECKT_DPOS 50    // Servo 1 Neck Top
#define S2_NECKB_DPOS 50    // Servo 2 Neck Bottom
#define S3_EYE_RHS_DPOS 50  // Servo eye RHS
#define S4_EYE_LHS_DPOS 50  // Servo eye LHS
#define S5_ARM_LHS_DPOS 50  // Servo Arm LHS
#define S6_ARM_RHS_DPOS 50  // Servo Arm RHS
#define S7_EYEB_RHS_DPOS 0  // Servo Eye Brow LHS Closed
#define S8_EYEB_LHS_DPOS 0  // Servo Eye Brow RHS Closed
#define S9_DOOR_DPOS 80     // Servo Door 0 = open, 100 closed

// PWM RGB LED channels on the PCA9685 16 Ch PWM module
#define RED_CHANNEL 13
#define GREEN_CHANNEL 14
#define BLUE_CHANNEL 15

// Motors L298N settings
#define PROG_RUN
#define MAX_SPEED 240       // sets speed of DC  motors
#define MAX_BACK_SPEED 240  // sets speed of DC  motors for backward movement
#define MAX_SPEED_OFFSET 0  // @ 20 Difference between left and right motor
#define turn_amount 750     //

// DFPlayer Speed
#define NORMAL_SPEED 1  // These are the playback speeds, change to
#define FAST_SPEED 1.5  // see the effect on the sound sample. 1 is default speed
#define SLOW_SPEED 2    // 0.75  // >1 faster, <1 slower, 2 would be twice as fast, 0.5 half as fast
#define PLAYFILES 17    // number of files on SD card

// Define other constants
#define NUMBER_OF_SERVOS 10      // Number of servo motors, 7 without eyelids, 9 with, plus door is 10
#define SERVO_UPDATE_TIME 10     // Time in milliseconds of how often to update servo and motor positions
#define SERVO_OFF_TIME 6000      // Turn servo motors off after 6 seconds
#define SERVOMIN 150             // This is the 'minimum' pulse length count (out of 4096)
#define SERVOMAX 600             // This is the 'maximum' pulse length count (out of 4096)
#define STATUS_CHECK_TIME 100    // Time in milliseconds of how often to check robot status (eg. battery level)
#define CONTROLLER_THRESHOLD 1   // The minimum error which the dynamics controller tries to achieve
#define MAX_SERIAL_LENGTH 5      // Maximum number of characters that can be received
#define ONESEC 1000              // One second dah
#define DISPLAY_IDEAL_TIME 5000  // display ideal 5 sec then home screen
#define OLED_ADDR 0x3C           //
#define LSTICK_DZ_Xmax 5         // Left Stick Dead Zone X Max...
#define LSTICK_DZ_Xmin -5        //
#define LSTICK_DZ_Ymax 5         // Left Stick Dead Zone Y Max...
#define LSTICK_DZ_Ymin -5        //
#define RSTICK_DZ_Xmax 5         // Right Stick Dead Zone...
#define RSTICK_DZ_Xmin -5        //
#define RSTICK_DZ_Ymax 5         //
#define RSTICK_DZ_Ymin -5        //

// OLED Display
SSD1306AsciiWire Oled;
#define DisplayFlip 1

// Servo shield controller class
Adafruit_PWMServoDriver pwm = Adafruit_PWMServoDriver();  //default address 0x40

// I/O Expander
Adafruit_PCF8575 pcf;  // default address= 0x20

// BLE Controller - Xbox gamepad
XboxController controller;

// Set up motor controller classes for L298 controller
MotorController motorL(DIRA1, ENABLE1, DIRA2, false);
MotorController motorR(DIRB1, ENABLE2, DIRB2, false);

// SpeedArray contains the order in which the code will playback the sample at the designated speeds
// This is not used anywhere, it is to do with DFplayer
float SpeedArray[] = { NORMAL_SPEED, FAST_SPEED, SLOW_SPEED };
uint8_t NoOfSpeeds = 1;  // Number of difference speeds in the Speed array above
uint8_t SpeedIdx = 0;    // In effect when the checks in the main loop are made this will increment to 0

// Sound Variables DFPlayer
bool soundPlaying = false;  //
bool playSoundTrigger = false;
bool isSound = true;          // Assume sound effects are available. Not realy used
bool playFilePBFlag = false;  // BLE_Gamepad.ino button down
uint8_t playIndex = 2;
uint8_t playIndexTotal = PLAYFILES;
uint8_t lastplayIndex = 2;


// Create Serial comms and DFPlayer
//HardwareSerial mySerial(1);  // Use UART1, this did not work with xbox
SoftwareSerial softSerial(/*rx =*/DFPLAYER_RX_PIN, /*tx =*/DFPLAYER_TX_PIN);
#define FPSerial softSerial
DFRobotDFPlayerMini myDFPlayer;

// Queue for animations - buffer is defined outside of the queue class
// so that the compiler knows how much dynamic memory will be used
struct animation_t {
  uint16_t timer;
  int8_t servos[NUMBER_OF_SERVOS];
};

#define QUEUE_LENGTH 50
animation_t buffer[QUEUE_LENGTH];
Queue<animation_t> queue(QUEUE_LENGTH, buffer);

// Motor Control Variables
int pwmspeed = 100;
int moveValue = 0;
int turnValue = 0;
int turnOffset = 0;
int motorDeadzone = 0;
int oldCurvel = 0;

// Runtime Variables
unsigned long lastTime = 0;
unsigned long animeTimer = 0;
unsigned long motorTimer = 0;
unsigned long statusTimer = 0;
unsigned long updateTimer = 0;
bool autoMode = false;
bool autonomousMode = false;  // ble interlock
bool autoModeFlag = false;
unsigned long autonomousModeTimer;  //for 1 sec led display
unsigned long LastBlinkLED;
bool stat_LED = false;
unsigned long displaytime = 0;
unsigned long doorTimer;
unsigned long debounceTimer;
bool doorMode = true;  // BLE interlock
bool doorFlag = false;
bool BLE_Conected_Flag = false;

uint8_t ledIndex = 0;  // PB Leds on body
uint8_t lastledIndex = 0;
uint8_t indexRGB = 0;

// Serial Parsing
char firstChar;
char serialBuffer[MAX_SERIAL_LENGTH];
uint8_t serialLength = 0;
String value = "";

// ****** SERVO MOTOR CALIBRATION *********************
// Servo Positions:  Low,High Range: 150-600 pause witdth2
int preset[][2] = { { 548, 192 },    // head rotation
                    { 185, 668 },    // neck top
                    { 370, 670 },    // neck bottom
                    { 165, 370 },    // eye right
                    { 650, 450 },    // eye left
                    { 520, 245 },    // arm left
                    { 368, 590 },    // arm right
                    { 380, 520 },    // Eyebrow Right
                    { 310, 170 },    // Eyebrow Left
                    { 680, 430 } };  // Door

// *****************************************************

// Servo Control - Position, Velocity, Acceleration
// Servo Pins:	     0,   1,   2,   3,   4,   5,   6,    7,   8, 9,  10,  11
// Joint Name:	  head,necT,necB,eyeR,eyeL,armL,armR,eyebL,eybR,Dr,motL,motR,
float curpos[] = { 248, 400, 140, 475, 270, 250, 290, 210, 307, 250, 180, 180 };    // Current position (units)
float setpos[] = { 248, 400, 140, 475, 270, 250, 290, 210, 307, 250, 0, 0 };        // Required position (units)
float curvel[] = { 0, 0, 0, 0, 0, 0, 0, 0, 0, 0, 0, 0 };                            // Current velocity (units/sec)
float maxvel[] = { 500, 500, 500, 1000, 1000, 500, 500, 600, 600, 500, 250, 250 };  // Max Servo velocity (units/sec)
float accell[] = { 350, 350, 350, 100, 100, 50, 50, 550, 550, 350, 800, 800 };      // Servo acceleration (units/sec^2)

//float maxvel[] = { 500, 400, 500, 2400, 2400, 600, 600, 400, 400, 250, 250, 500 };  // Max Servo velocity (units/sec)
//float accell[] = { 350, 300, 480, 1800, 1800, 500, 500, 300, 300, 800, 800, 350 };  // Servo acceleration (units/sec^2)

//-----------------------------------
// BLE Game controler default Values
uint8_t neckBottomIndex = S2_NECKB_DPOS;
uint8_t eyeRHSIndex = S3_EYE_RHS_DPOS;
uint8_t eyeLHSIndex = S4_EYE_LHS_DPOS;
uint8_t leftArmIndex = S5_ARM_LHS_DPOS;
uint8_t rightArmIndex = S6_ARM_RHS_DPOS;
uint8_t eyebrowRHSIndex = S7_EYEB_RHS_DPOS;
uint8_t eyebrowLHSIndex = S8_EYEB_LHS_DPOS;

bool leftBrowPB = false;
bool rightBrowPB = false;

bool animationPBFlag = false;
uint8_t animationIndex = 0;
uint8_t LastAnimationIndex = 99;

bool steeringoffsetPBFlag = false;
int16_t steeringIndex = 0;
int16_t LaststeeringIndex = 99;

bool motorDeadZonePBFlag = false;
uint8_t motorDeadZoneIndex = 0;
uint8_t LastmotorDeadZoneIndex = 0;

int16_t lastleftStickX = 50;
int16_t lastleftStickY = 50;
int16_t lastleftArm = 50;
int16_t lastrightArm = 50;
int16_t lastnecktop = 50;
int16_t lasteyeLHS = 50;
int16_t lasteyeRHS = 50;

bool neutral_LHS_JS_X = true;
bool neutral_LHS_JS_Y = true;
bool neutral_RHS_JS_X = true;
bool neutral_RHS_JS_Y = true;

// -------------------------------------------------------------------
// Initial setup
// -------------------------------------------------------------------
void setup() {
  Serial.begin(115200);
  Serial.print(F("--- Wall-E Control Sketch - V"));
  Serial.print(VERSION);
  Serial.println(F(" ---"));
  delay(1000);

  // Output Enable (EO) pin for the servo motors
  pinMode(SERVO_ENABLE_PIN, OUTPUT);
  digitalWrite(SERVO_ENABLE_PIN, HIGH);

  // Motor pins
  pinMode(DIRA1, OUTPUT);
  pinMode(DIRB1, OUTPUT);
  pinMode(ENABLE1, OUTPUT);
  pinMode(DIRA2, OUTPUT);
  pinMode(DIRB2, OUTPUT);
  pinMode(ENABLE2, OUTPUT);
  digitalWrite(DIRA1, HIGH);
  digitalWrite(DIRB1, HIGH);
  digitalWrite(DIRA2, HIGH);
  digitalWrite(DIRB2, HIGH);
  digitalWrite(ENABLE1, HIGH);
  digitalWrite(ENABLE2, HIGH);

  // Communicate with servo shield (Analog servos run at ~60Hz)
  pwm.begin();
  pwm.setPWMFreq(60);

  // Turn off servo outputs
  for (int i = 0; i < NUMBER_OF_SERVOS; i++) {
    pwm.setPin(i, 0);
  }

  //BLE xbox controler
  controller.begin();
  delay(1000);

  // OLED Display
  Oled.begin(&Adafruit128x64, OLED_ADDR);  // 0.96 Inch mono display
  Oled.displayRemap(DisplayFlip);          // set true or false to flip screen
  oledWelcome();

  // START the PCF8575 Expander
  if (!pcf.begin(0x20, &Wire)) {
    Serial.println("Couldn't find PCF8575");
    while (1)
      delay(100);
  }
  delay(1000);

  pcf.pinMode(PIN_RED_PB, INPUT_PULLUP);    //
  pcf.pinMode(PIN_GRN_PB, INPUT_PULLUP);    //
  pcf.pinMode(PIN_ORG_PB, INPUT_PULLUP);    //
  pcf.pinMode(PIN_WHT_PB, INPUT_PULLUP);    //
  pcf.pinMode(PIN_DFP_BUSY, INPUT_PULLUP);  //

  pcf.pinMode(PIN_RED_LED, OUTPUT);  // active low
  pcf.pinMode(PIN_GRN_LED, OUTPUT);  //
  pcf.pinMode(PIN_ORG_LED, OUTPUT);  //
  pcf.pinMode(PIN_WHT_LED, OUTPUT);  //
  pcf.pinMode(PIN_BAY_LED, OUTPUT);  // active high

  alloff();  // all PushButton leds off
  delay(1000);

  // START DFPlayer
  Serial.println("Staring DFPlayer...");
  //mySerial.begin(9600, SERIAL_8N1, D7, D6);  // RX = D7, TX = D6 (hardware serial)
  FPSerial.begin(9600);  // Software serial
  delay(1000);
  //myDFPlayer.begin(mySerial);   // HW Serial
  myDFPlayer.begin(FPSerial, /*isACK = */ true, /*doReset = */ true);  //SW Serial
  delay(4000);                                                         // it needs time to read SD card and start up
  //if (!myDFPlayer.begin(mySerial)) {    //HW serial
  if (!myDFPlayer.begin(FPSerial)) {  //SW serial
    isSound = false;                  // If failed, no sound available : continue
    Serial.println(myDFPlayer.readType(), HEX);
    Serial.println(F("Error with DFPlayer."));
  } else {
    Serial.println(F("DFPlayer Mini online."));
    myDFPlayer.setTimeOut(500);  //Set serial communictaion time out 500ms
    delay(4000);                 // this is needed, else might not start

    //----Set volume----
    myDFPlayer.volume(30);    // Set volume value (0~30).
    myDFPlayer.volumeUp();    // Volume Up
    myDFPlayer.volumeDown();  // Volume Down
    myDFPlayer.EQ(DFPLAYER_EQ_NORMAL);
    myDFPlayer.outputDevice(DFPLAYER_DEVICE_SD);

    soundPlaying = true;
    myDFPlayer.play(playIndex);  //Play the mp3 (file: 2 sounds good)
  }

  randomSeed(analogRead(0));

  // Check if servo animation queue is working, and move servos to known starting positions
  if (queue.errors()) Serial.println(F("Error: Unable to allocate memory for servo animation queue"));

  // Soft start the servo motors
  Serial.println(F("Starting up the servo motors"));
  digitalWrite(SERVO_ENABLE_PIN, LOW);

  //  Set servo defaults here
  // servoDefaults();
  playAnimation(0);              // case 0 loads servo default positions
  softStart(queue.pop(), 3500);  // trigger queue

  Serial.println(F("Startup complete; entering main loop"));
}

//==========================================================================================================
// ---------------------------------------------
// transfers BLE commands to serial interface
// ---------------------------------------------
void doEvaluateSerial(char fs, String val) {  // val is, value converting to string
  firstChar = fs;
  serialLength = 0;
  for (uint8_t i = 0; i < val.length() && i < MAX_SERIAL_LENGTH - 1; i++) {  // get length of string pased in val
    serialBuffer[i] = val[i];                                                // load serial buffer at i with char at val(i), this is the hock in
    serialLength++;
  }
  serialBuffer[serialLength] = 0;
  // Serial.print(" fs = ");
  //  Serial.print(fs);
  //  Serial.print(" serialBuffer = ");
  //  Serial.print(serialBuffer);
  //  Serial.print(", ");

  evaluateSerial();  // read serial buffer (CLI)
  serialBuffer[0] = 0;
  serialBuffer[1] = 0;
  serialBuffer[2] = 0;
  serialBuffer[3] = 0;
  serialBuffer[4] = 0;
}

// -------------------------------------------------------------------
// Read input from USB serial port
//
// This function reads incoming characters in the serial port
// and inserts them into a buffer to be processed later.
// -------------------------------------------------------------------
void readSerial() {
  char inchar = Serial.read();             // Read incoming USB byte
  if (inchar == '\n' || inchar == '\r') {  // If the string has ended, evaluate the serial buffer
    if (serialLength > 0) evaluateSerial();
    serialBuffer[0] = 0;
    serialLength = 0;
  } else {  // Otherwise add to the character to the buffer
    if (serialLength == 0) firstChar = inchar;
    else {
      serialBuffer[serialLength - 1] = inchar;
      serialBuffer[serialLength] = 0;
    }
    serialLength++;
    if (serialLength == MAX_SERIAL_LENGTH) {  // To prevent overflows, evalute the buffer if it is full
      evaluateSerial();
      serialBuffer[0] = 0;
      serialLength = 0;
    }
  }
}
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
void loop() {
  if (Serial.available() > 0) {                       // Read any new serial messages
    readSerial();                                     //
  }                                                   //
  manageAnimations();                                 // Read any new serial messages
  if (millis() - updateTimer >= SERVO_UPDATE_TIME) {  // Move Servos and wheels at regular time intervals
    updateTimer = millis();
    unsigned long newTime = micros();
    float dt = (newTime - lastTime) / 1000.0;
    lastTime = newTime;
    manageServos(dt);
    manageMotors(dt);
  }
  if (millis() - statusTimer >= STATUS_CHECK_TIME) {  // Update robot status
    statusTimer = millis();                           //
    PCF8575_Update();                                 // update expander i/o
    processSound();                                   //
     if (!soundPlaying) {Controler();}                // get xbox control update
    DisplayIdeal();                                   // if display ideal goto home screen
    processPB_LEDS();                                 //
    ProcessBlinkLED_org();                            //
  }
}

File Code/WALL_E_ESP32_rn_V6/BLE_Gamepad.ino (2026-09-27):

/* * * * * * * * * * * * * * * * * * * * * * *
 * Update BLE controller status
 *
 * Code by:  Richard Nicholson
 * Email:    richn01@msn.com
 * based on the original project from Simon Bluett ( hello@chillibasket.com )
 * Version:  1.0
 * Date:     23 July 2026
 * Copyright (C) 2020, MIT License
 * * * * * * * * * * * * * * * * * * * * * * */

void Controler() {  // read xbox buttons and sticks, 100ms interval

  int controllerAddress;
  int leftStickX;         // Left Stick X: Head rotation
  int leftStickY;         // Left Stick Y: Head Up/Down - Neck Bottom servo
  int rightStickX;        // Right Stick X: Wall-E Motors turn left/right
  int rightStickY;        // Right Stick Y: Wall-E Motors forward/back
  bool leftStickButton;   //
  bool rightStickButton;  // Autonomus Mode on/off
  bool buttonA;           // Neck Top - A + L JS
  bool buttonX;           // Lhs Eye - X + L JS
  bool buttonB;           // Rhs Eye - B + L JS
  bool buttonY;           // Door Open/Close toggle - Y
  bool leftBumper;        // LHS Eye Brrow Flap open/close
  bool rightBumper;       // RHS Eye Brow Flap open/close
  bool leftTrigger;       // Left Arm move Up/Down - LT + L JS
  bool rightTrigger;      // Right Arm  move Up/Down - RT + L JS
  bool dpadUp;            // adjust up
  bool dpadDown;          // adjust down
  bool dpadLeft;          // adjust left
  bool dpadRight;         // adjust right
  bool menuButton;        // Animation Number #
  bool viewButton;        // Dead Zone #
  bool shareButton;       // Steering Offset #
  bool xboxButton;        // 

  // Is controller connected
  if (controller.isConnected()) {
    if (!BLE_Conected_Flag) {
      BLE_Conected_Flag = true;
      Serial.println("controller CONNECTED");
      oledxbox(BLE_Conected_Flag);
    }
    XboxControlsState s;
    controller.read(&s);

    // read current values to local variable names
    controllerAddress = s.controllerAddress;
    leftStickX = (s.leftStickX * 100);
    leftStickY = (s.leftStickY * 100);
    rightStickX = (s.rightStickX * 100);
    rightStickY = (s.rightStickY * 100);
    leftStickButton = s.leftStickButton;
    rightStickButton = s.rightStickButton;
    dpadUp = s.dpadUp;
    dpadDown = s.dpadDown;
    dpadLeft = s.dpadLeft;
    dpadRight = s.dpadRight;
    buttonA = s.buttonA;
    buttonB = s.buttonB;
    buttonX = s.buttonX;
    buttonY = s.buttonY;
    leftBumper = s.leftBumper;
    rightBumper = s.rightBumper;
    leftTrigger = s.leftTrigger;
    rightTrigger = s.rightTrigger;
    shareButton = s.shareButton;
    menuButton = s.menuButton;
    viewButton = s.viewButton;
    xboxButton = s.xboxButton;

    //----------------------------------------------------
    // Play File  - Left Trigger & right Trigger + Dpad up/down - CLI: !n 1-17 (playindextotal)
    // need to do this here to stop serial conflick with DFP = crash
    if (leftTrigger && rightTrigger) {
      playFilePBFlag = true;
      if ((playIndex == lastplayIndex) && (displaytime == 0)) {  // display current index if not already
        OledPlayFile(playIndex);
      }
      if (dpadUp) {
        playIndex++;
        if (playIndex >= (playIndexTotal + 1)) { playIndex = 1; }
        if (playIndex == 0) { playIndex = 1; }
        OledPlayFile(playIndex);
      }
      if (dpadDown) {
        playIndex--;
        if (playIndex == 255) { playIndex = playIndexTotal; }
        if (playIndex == 0) { playIndex = 1; }
        OledPlayFile(playIndex);
      }
      goto bailout;
    }
    if ((!leftTrigger && !rightTrigger) && playFilePBFlag) {
      playFilePBFlag = false;
      //lastplayIndex = playIndex;
      if (!soundPlaying) {    
        OledPlayFile(playIndex);   
        playSoundTrigger = true;
      }
      //value = String(playIndex);
      //doEvaluateSerial('!', value);  // send new value
      goto bailout;
    }


    //----------------------------------------------------------------------------
    // Display Both JS readings - De bug only
    //
    //Serial.printf("lstick: %.2f,%.2f, rstick: %.2f,%.2f\n",
    //              s.leftStickX, s.leftStickY, s.rightStickX, s.rightStickY);
    //----------------------------------------------------------------------------

    //----------------------------------------------------------------
    // TRACKS - Right Joy Stick X --- Motor turn Left/Right CLI: Xn -100 to 100
    if ((rightStickX >= RSTICK_DZ_Xmax) || (rightStickX <= RSTICK_DZ_Xmin)) {
      value = String(map(rightStickX, -100, 100, 100, -100));  //convert signal to correct way around
      doEvaluateSerial('X', value);
      neutral_RHS_JS_X = false;
    } else {
      if (!neutral_RHS_JS_X) {
        doEvaluateSerial('X', String(0));
        neutral_RHS_JS_X = true;
      }
    }

    //----------------------------------------------------------------
    // TRACKS Right Joy Stick Y --- Motor Forward/Reverse CLI: Yn -100 to 100
    if ((rightStickY >= RSTICK_DZ_Ymax) || (rightStickY <= RSTICK_DZ_Ymin)) {
      doEvaluateSerial('Y', String(rightStickY));
      neutral_RHS_JS_Y = false;
    } else {
      if (!neutral_RHS_JS_Y) {
        doEvaluateSerial('Y', String(0));
        neutral_RHS_JS_Y = true;
      }
    }

    //---------------------------------------
    // Neck Top - A + Left JS - CLI: Tn 0-100
    if (buttonA) {
      if ((leftStickY != lastnecktop) && ((leftStickY >= LSTICK_DZ_Ymax) || (leftStickY <= LSTICK_DZ_Ymin))) {
        lastnecktop = leftStickY;
        value = String(map(leftStickY, -100, 100, 0, 100));
        doEvaluateSerial('T', value);
        neutral_LHS_JS_Y = false;  // not in neutral zone
        goto bailout;
      } else {  // is in now in neutral zone
        if ((!neutral_LHS_JS_Y) && (leftStickY != lastnecktop)) {
          doEvaluateSerial('T', String(50));
          neutral_LHS_JS_Y = true;
          lastnecktop = leftStickY;
          goto bailout;
        }
        goto bailout;
      }
      goto bailout;
    }

    //---------------------------------------
    // Lhs Eye - X + JS - CLI: En 0 to 100
    else if (buttonX) {
      if ((leftStickY != lasteyeLHS) && ((leftStickY >= LSTICK_DZ_Ymax) || (leftStickY <= LSTICK_DZ_Ymin))) {
        lasteyeLHS = leftStickY;
        value = String(map(leftStickY, -100, 100, 0, 100));
        doEvaluateSerial('E', value);
        neutral_LHS_JS_Y = false;  // not in neutral zone
        goto bailout;
      } else {  // is now in neutral zone or holding
        if ((!neutral_LHS_JS_Y) && (leftStickY != lasteyeLHS)) {
          doEvaluateSerial('E', String(50));
          neutral_LHS_JS_Y = true;
          lasteyeLHS = leftStickY;
          goto bailout;
        }
        goto bailout;
      }
      goto bailout;
    }
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
